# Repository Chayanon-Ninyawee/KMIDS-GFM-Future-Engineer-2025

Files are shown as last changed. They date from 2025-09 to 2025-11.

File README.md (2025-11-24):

# Hello! We are **Team KMIDS-GFM**.

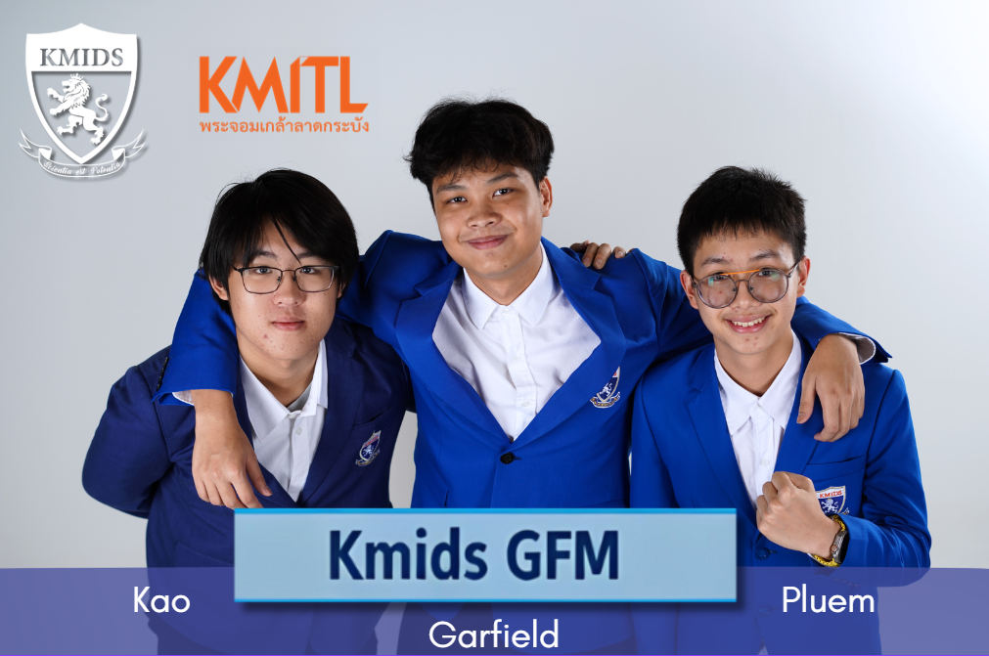
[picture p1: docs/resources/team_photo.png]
Team Photo


# WRO - Future Engineers - Robotics Project Documentation

## Team Members

- **Chayanon Ninyawee (Garfield)**
- **Supakorn Sunthonthammarat (Pleum)**
- **Thammatouch Chantasarn (Kao)**

We are a team of dedicated students with a passion for robotics and innovation. This repository documents our full engineering process, including design, components used, development, testing, and coding of our robot.

## Table of Contents

<!-- toc -->

- [1. Overview](#1-overview)
  - [1.1 About the Project](#11-about-the-project)
  - [1.2 Robot Images](#12-robot-images)
  - [1.3 Performance Video](#13-performance-video)
- [2. Mobility Management](#2-mobility-management)
  - [2.1 Drive System](#21-drive-system)
  - [2.2 Steering](#22-steering)
  - [2.3 Chassis Design](#23-chassis-design)
- [3. Power and Sense Management](#3-power-and-sense-management)
  - [3.1 Power Source](#31-power-source)
  - [3.2 Sensor and Camera](#32-sensor-and-camera)
  - [3.3 Processing Units](#33-processing-units)
  - [3.4 Circuit Diagram](#34-circuit-diagram)
  - [3.5 Power Consumption](#35-power-consumption)
- [4. Obstacle Management](#4-obstacle-management)
  - [4.1 Open Challenge](#41-open-challenge)
  - [4.2 Obstacle Challenge](#42-obstacle-challenge)
  - [4.3 Parallel Parking](#43-parallel-parking)
- [5. Source Code](#5-source-code)
  - [5.1 API Documentation](#51-api-documentation)
  - [5.2 Code Structure](#52-code-structure)
  - [5.3 Compilation / Upload Instructions](#53-compilation--upload-instructions)
- [6. List of Components](#6-list-of-components)
- [7. 3D Model Files](#7-3d-model-files)
  - [7.1 FreeCAD Files](#71-freecad-files)
  - [7.2 STL Files](#72-stl-files)
  - [7.3 Slicer Files](#73-slicer-files)
- [8. Building Instructions](#8-building-instructions)
- [9. Extras](#9-extras)

<!-- tocstop -->

## 1. Overview

### 1.1 About the Project

This project focuses on designing, building, and programming an autonomous robot capable of completing a series of complex obstacle challenges as part of the WRO Future Engineers competition.

Team KMIDS-GFM was inspired by the challenge of applying engineering principles and problem-solving skills to creatively and efficiently solve complex problems. Pushing forward with our passion for innovation and hands-on learning.

Our goal is to design and build a reliable and efficient system that demonstrates our technical and collaborative skills while serving as a learning experience. We followed a systematic process, including brainstorming, researching, prototyping, testing, and iterating. We maintained detailed documentation to facilitate knowledge sharing and ensure a smoother workflow throughout the project.

Our robot is engineered using a custom modular chassis in a rear-wheel drive configuration, controlled using a Raspberry Pi 5 and a Raspberry Pi Pico 2. It utilizes a combination of an LIDAR sensor and a fish-eye lens camera to provide an advanced system for obstacle detection and navigation.

Our objective is to create an intelligent robot that is capable of navigating through obstacles with pinpoint precision and speed.

### 1.2 Robot Images

<table>
  <tr>
    <td align="center">
      <b>Front View</b><br>
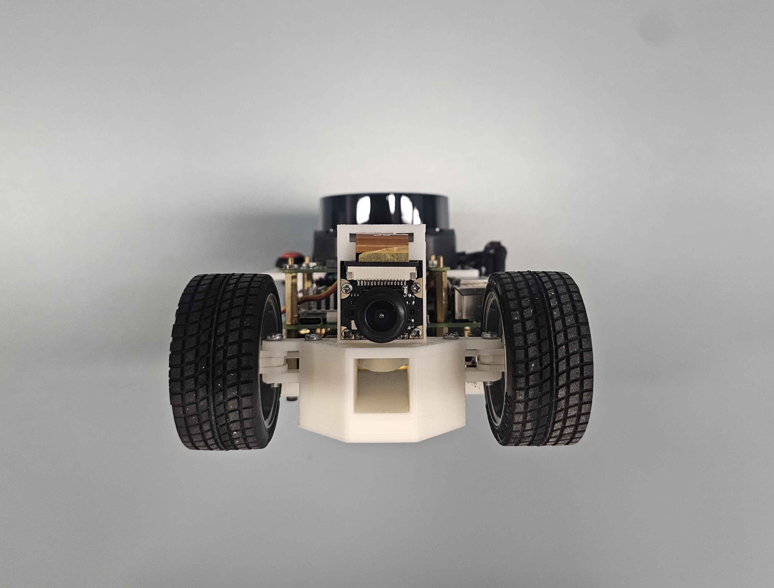
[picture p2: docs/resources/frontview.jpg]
      
    </td>
    <td align="center">
      <b>Back View</b><br>
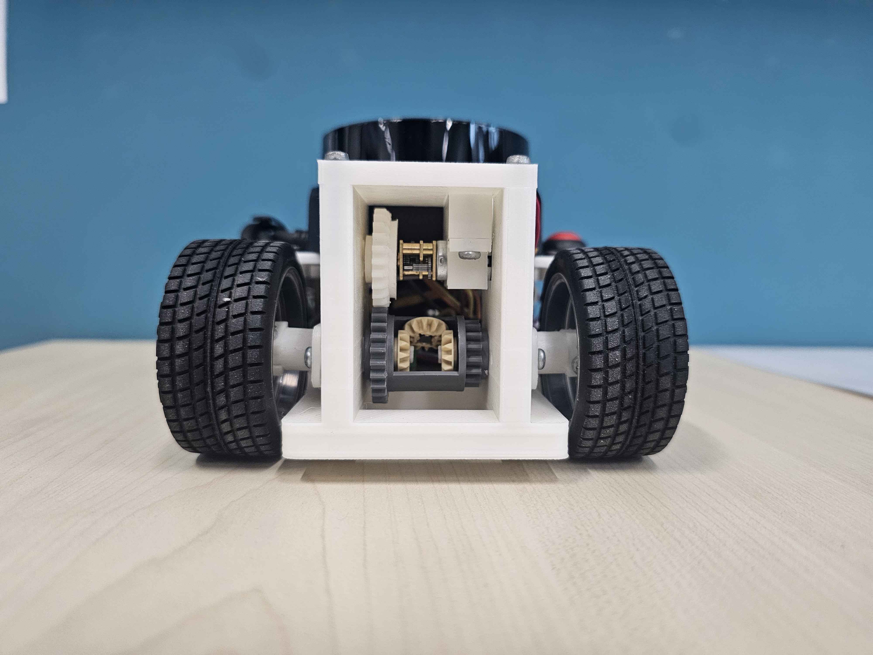
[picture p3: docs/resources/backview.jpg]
      
    </td>
    <td align="center">
      <b>Left Side View</b><br>
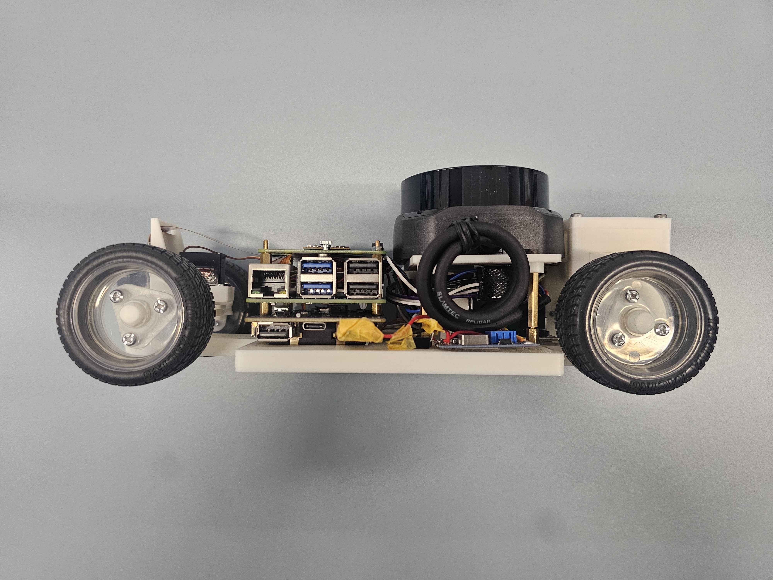
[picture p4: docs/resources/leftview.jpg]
      
    </td>
  </tr>
  <tr>
    <td align="center">
      <b>Right Side View</b><br>
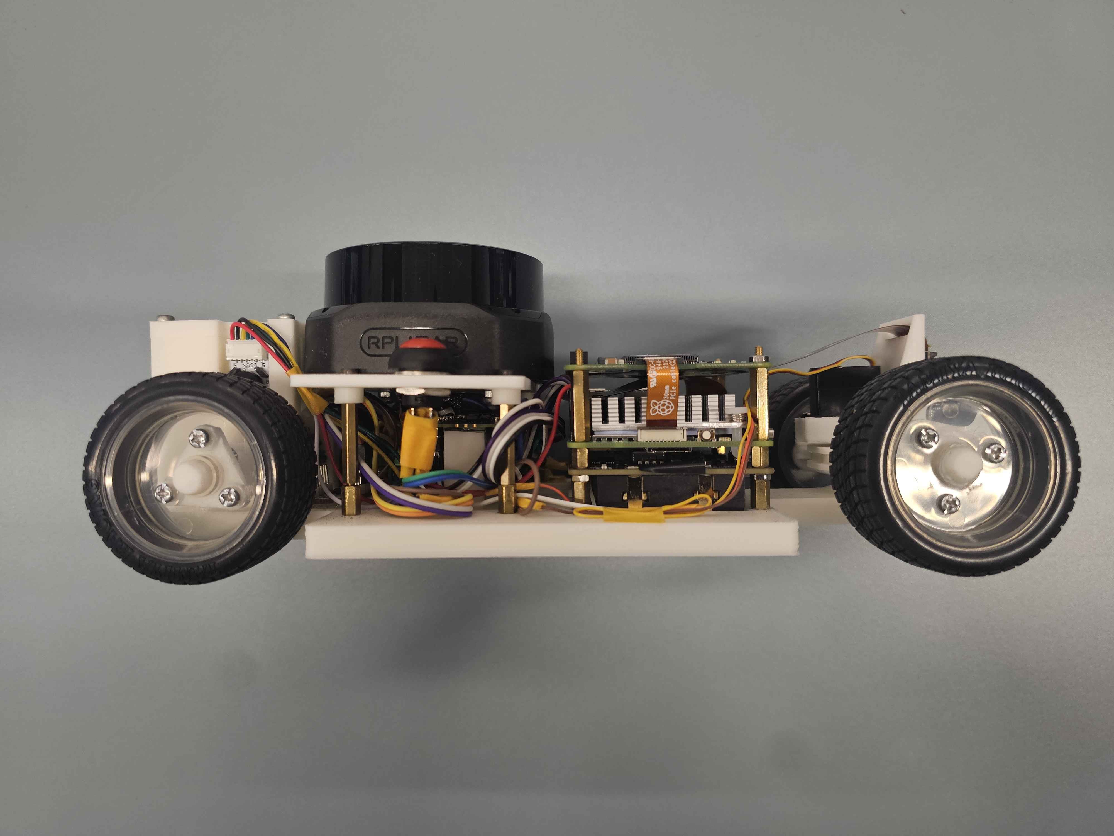
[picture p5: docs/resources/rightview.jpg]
      
    </td>
  <td align="center">
  <b>Top View</b><br>
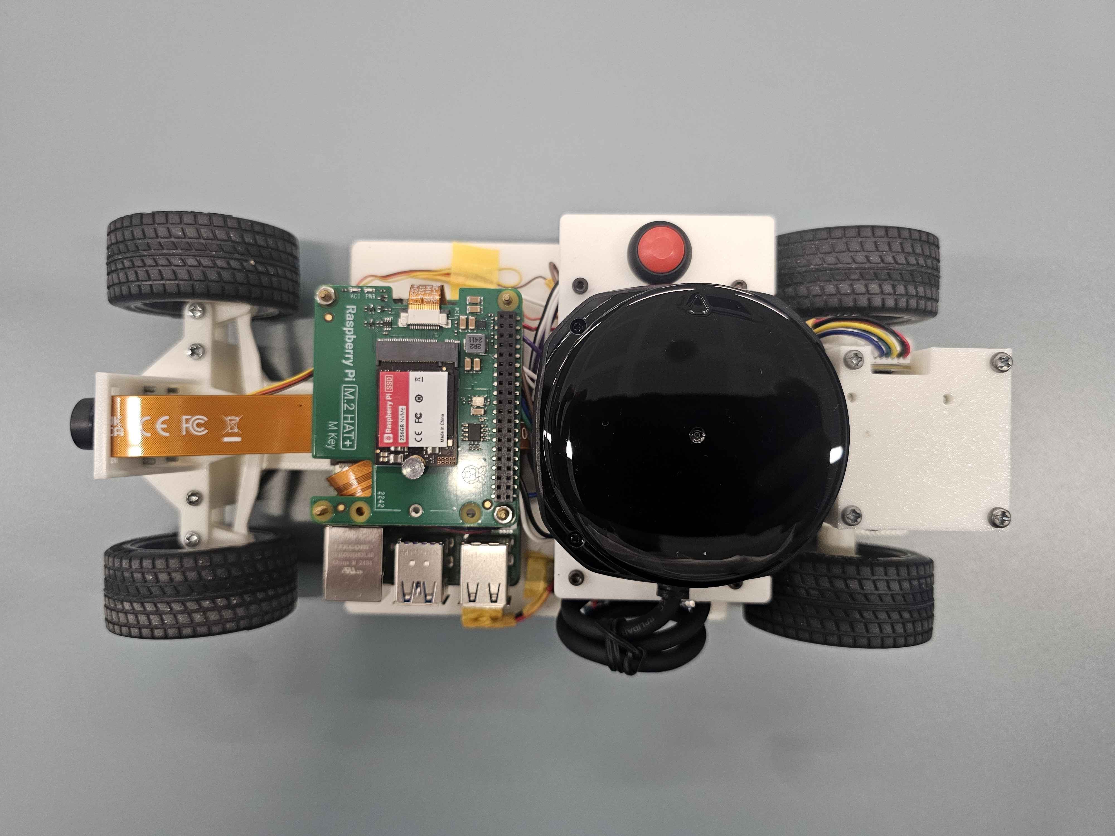
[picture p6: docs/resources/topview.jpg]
  
</td>
    <td align="center">
      <b>Bottom View</b><br>
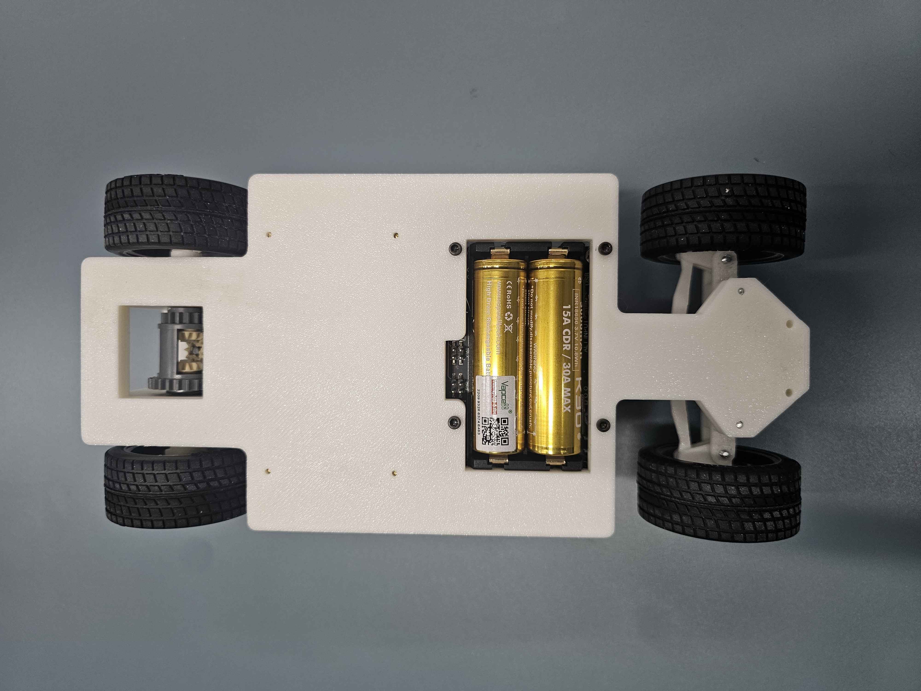
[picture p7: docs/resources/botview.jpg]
      
    </td>
  </tr>
</table>

### 1.3 Performance Video

[Part 1: Open Challenge Video](https://youtu.be/gOz7pKEmLP0)

[Part 2: Obstacle Challenge Video](https://youtu.be/q8gWAhReJgc)

These two parts show both the Open and Obstacle Challenges respectively.

<p align="right">
  <a href="#top">Back To Top</a>
</p>

## 2. Mobility Management

- **Drive System:** 2-wheel differential drive (rear wheels).
- **Steering:** Front-wheel steering using S0009m servo.

### 2.1 Drive System

**Motor: N20 Motor**

<table>
  <tr>
    <td align="center" width="300" >
      
    </td>
    <td>
      <h3>Specifications:</h3>
      <ul>
        <li>Voltage: 6V </li>
        <li>No-load Speed: 500RPM </li>
        <li>Stall Torque 0.15kg-cm</li>
        <li>Current: 0.023A</li>
        <li>Gear Ratio: 1:100</li>
      </ul>
    </td>
  </tr>
</table>

**Reason for Selection:**

- It is compact and lightweight, allowing us to fit it into our robot easily.
- Provides moderate torque that is more than enough for the flat arena.
- Easy to use on the robot and integrate with other parts.

The N20 motor is equipped with an encoder to provide precise motion feedback, ensuring the robot’s movements are accurate. The motor drives the rear wheels through a LEGO differential gear system, which allows the robot to maintain smooth and balanced turns even at higher speeds. By distributing torque between the two wheels, the differential minimizes wheel slip and ensures stability during sharp maneuvers.
The integration of encoders with the N20 motors provides real-time feedback for closed-loop control, enabling precise speed regulation and consistent lap performance. Although the torque of the N20 is modest, the combination with the differential gear makes it well-suited for the flat and predictable competition arena, striking a balance between efficiency, stability, and mechanical simplicity.

**Differential Gear:**

We used a LEGO differential gear system on our robot which allows the left and right rear wheels to rotate at different speeds while turning, preventing tire drag and ensuring smoother turning. This setup enhances maneuverability and stability, especially during tight turns in the obstacle challenge and during parallel parking.

**Mounting:**

- Installed using 3D-printed motor clamps screwed to a detachable motor plate that is placed above the differential gear compartment. This will allow for future changes to accommodate bigger motors and gears. [Motor Clamp](./FreeCAD-Files/Assembly/mesh_export/MotorHolder_1x.stl) [Motor Plate](./FreeCAD-Files/Assembly/mesh_export/MotorPlate_1x.stl)

diff gear

- Wires connected to Raspberry Pi Pico 2.
- Rubber wheels are screwed onto the motor shaft.

**Considerations:**
To reach a faster speed, we can upgrade the N20 motor to the N30, which is the easiest upgrade, providing an overall improvement in speed and torque. However, the N30 motor is typically larger and such, might need extra modifications to the robot's chassis and motor clamp to fit properly. It also generally operates at higher voltages and currents, so the power supply needs to be modified to support this upgrade.

### 2.2 Steering



**Servo: S0009M**

<table>
  <tr>
    <td align="center" width="300" >
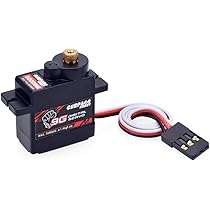
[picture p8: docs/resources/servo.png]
      
    </td>
    <td> 
      <h3>Specifications:</h3>
      <ul>
          <li>Rated Torque: 1.1kgf/cm</li>
          <li>Speed: 0.15sec/60°</li>
          <li>Voltage: 5V</li>
          <li>Gearing: Metal</li>
          <li>Type: Digital </li>
      </ul>
    </td>
  </tr>
</table>

**Reason for Selection:**

- The small size and PWM interface make it easy to control via Raspberry Pi Pico 2.
- It has sufficient torque to steer the front wheels responsively.
- It has balanced speed and stability during turns and lane changes.
- This servo is widely used in hobby robotics, and as such, there is much available documentation and mounting kits.

We considered many steering systems, but following our design principle of precision, we decided to implement Ackermann steering geometry to better replicate the precise turning behavior of real-world vehicles.

Unlike simpler systems, Ackermann steering has the advantage of smoother turns by moving each wheel at different angles in a turn, reducing the slippage of the tires and improving turn accuracy.

The fundamental principle of Ackermann geometry involves positioning the steering linkage so that a line drawn through both front wheels intersects the rear axle of the robot.



While this steering geometry is complex to implement, we believe that the advantages it provides are important — especially in obstacle navigation and parking, where precise control and a minimized turning radius are essential. It enables smoother maneuvering and accurate alignment in narrower spaces.

Our implementation comes in the form of a custom 3D-printed Ackermann steering mechanism, which offers the following key aspects:

- We used FreeCAD to experiment with different pivot points and steering angles step by step.
- Although true Ackermann geometry is difficult to achieve at our robot's small scale, we aimed to approximate the behavior through multiple design iterations.
- Adjustments were made to the servo horns and steering angles directly in CAD before testing.

**Calibration and Implementation**

To make sure the steering angle performed correctly, we carried out an iterative calibration process:

- We manually adjusted the servo horn angle and linkage positions step by step in FreeCAD until the wheels aligned at the desired steering angle.
- After each adjustment, we observed whether the wheels tracked correctly in both directions.
- Once the optimal angle is reached, we make sure to model the steering mechanism around the angle.

**Mounting:**

- Screwed directly into a platform plate in front of the chassis, connected to the steering mechanism.

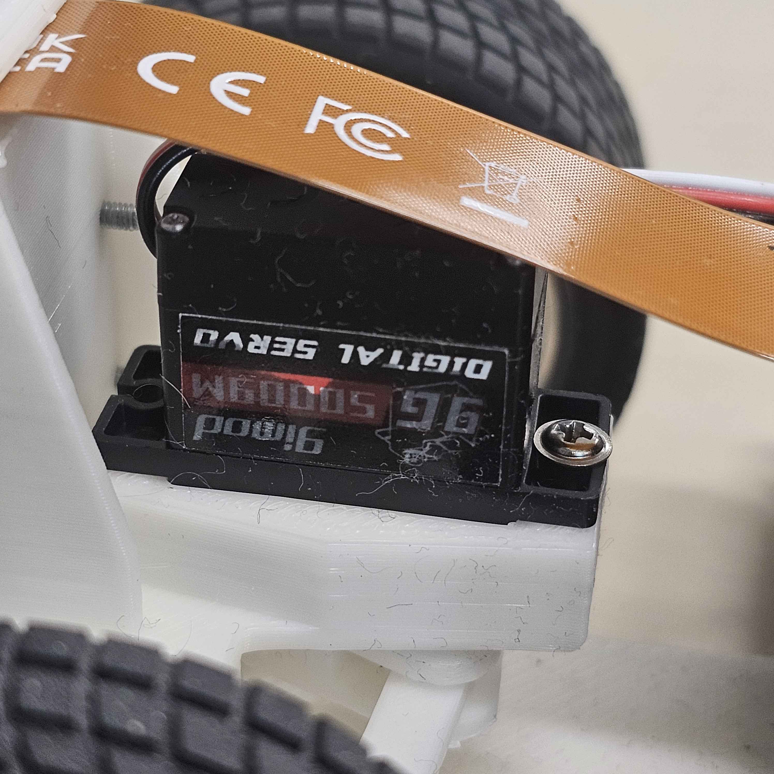
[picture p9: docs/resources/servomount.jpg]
Servo Mounting


**Considerations**
While the servo used is adequate for the task, it can still be replaced with something more precise. We plan to upgrade to a high-resolution digital servo with a narrower deadband and metal gears for more accurate movement. By also integrating a PWM driver such as the PCA9685, we gain 12-bit resolution control, which gives the robot the ability to make finer adjustments than the Raspberry Pi’s native PWM.

### 2.3 Chassis Design

**Chassis Overview:**

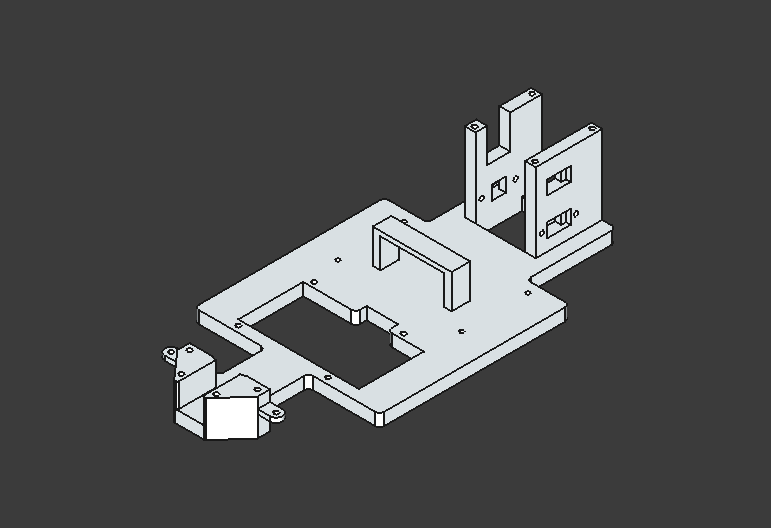
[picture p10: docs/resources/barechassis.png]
chassis


| Dimension | Value (mm) |
| --- | --- |
| Width | 244 |
| Length | 120 |
| Height | 59 |

**Design Overview**

Our chassis was designed with a focus on weight and modularity. The goal is for our chassis to be a stable platform on which we can implement the steering geometry while also allowing components to remain centered on the chassis.

**Layout**

The layout of the chassis is made to fit the rear-mounted motors and front-mounted steering mechanism. Meanwhile, electronics and sensors are mounted in the center for ease of wiring.

Our robot chassis was completely custom-designed in FreeCAD and 3D printed using [esun PLA+](https://esun3dstore.com/products/pla-pro), which we found is easy to print with, offering a smoother texture and less warping compared to ABS, while also being lightweight and durable. Alongside the main chassis, the drivetrain and steering modules are mounted on our 3D-printed detachable plates that were fine-tuned during testing to achieve the correct alignment with other components. Other components, such as motor clamps and sensor brackets, are designed as independent printable components. The chassis was also designed with modularity in mind for replacements and upgrades, with reduced overhangs for printing ease.

<p align="right">
  <a href="#top">Back To Top</a>
</p>

## 3. Power and Sense Management

### 3.1 Power Source

**Battery: 18650 Lithium-ion**

<table>
  <tr>
    <td align="center" width="300" >
      
    </td>
    <td>
      <h3>Specifications:</h3>
      <ul>
          <li>Capacity: 2000 mAh</li>
          <li>Normal voltage: 3.7V</li>
          <li>Standard discharge: 10A </li>
          <li>Weight: 48g</li>
      </ul>
    </td>
  </tr>
</table>

The power and sensor systems are crucial to the vehicle's ability to navigate the challenges of the competition. For this project, our vehicle is powered by an [EP-0136 Raspberry Pi UPS](https://wiki.52pi.com/index.php?title=EP-0136) (Uninterruptible Power Supply), with 2x 18650 Lithium-ion as the energy source. The UPS maintains a stable 5V output to the Raspberry Pi 5 even during fluctuations. It also has built-in charging and voltage regulation circuits, allowing continuous operation while also recharging the batteries when external power is connected.
The batteries are connected in series to provide a nominal voltage of 7.4V and a combined capacity of around 4000 mAh, depending on the cells used. This setup is capable of delivering a continuous current of around 20 Amps, which is sufficient to supply to the robot for various tasks. This setup ensures that the Raspberry Pi won't shut down unexpectedly, allowing uninterrupted data processing and decision-making throughout the run.

The motors, however, require a higher voltage — at least 6V, and to ensure reliable performance, the N20 motor power is supplied through a step-up converter that increases 5V to 12V. Because the motor power is separate from the Raspberry Pi, the standard on/off switch could not fully control the system. To solve this, a MOSFET and a 4.4 kΩ resistor were added between the gate and source, with the drain connected to the negative side of the step-up converter. This allows the robot to be safely powered on and off while supplying sufficient power to both the Raspberry Pi and the motors.

The onboard processing unit, the Raspberry Pi 5, serves as the vehicle's brain. Raspberry Pi recommends a 5V 5A power supply. This is well within the limits of what the two batteries can provide.

 

**Motor Driver: DRV8871**

<table>
  <tr>
    <td align="center" width="300">
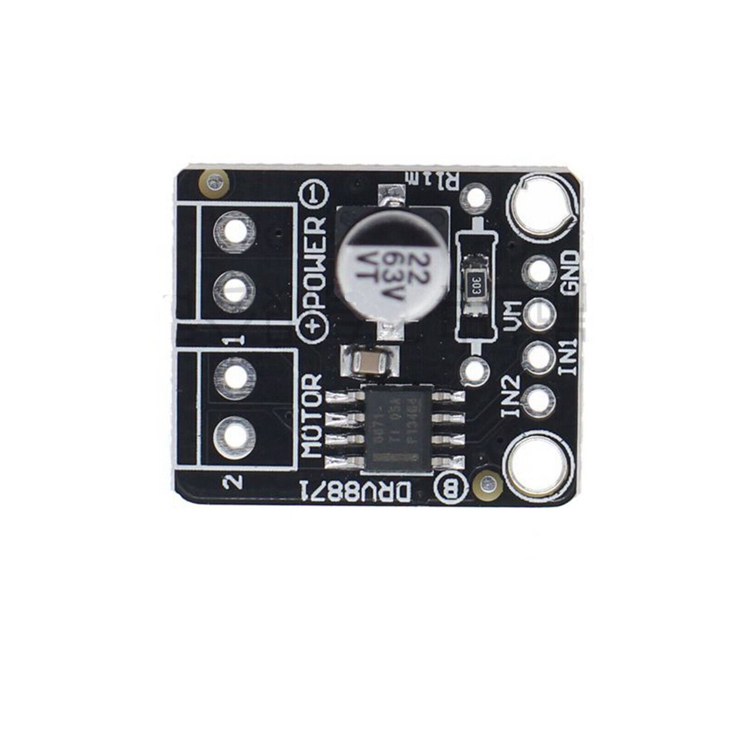
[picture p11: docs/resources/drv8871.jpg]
      
    </td>
    <td>
      <h3>Specifications:</h3>
      <ul>
          <li>Operating Voltage Range: 6.5V – 45V</li>
          <li>Peak Output Current: 3.6A</li>
          <li>Typical R<sub>DS(on)</sub> (high + low): 565mΩ</li>
          <li>Logic Level Input Voltage: Up to 5.5V on IN pins </li>
      </ul>
      </ul>
    </td>
  </tr>
</table>

**Transistor: N-Channel MOSFET**

<table>
  <tr>
    <td align="center" width="300">
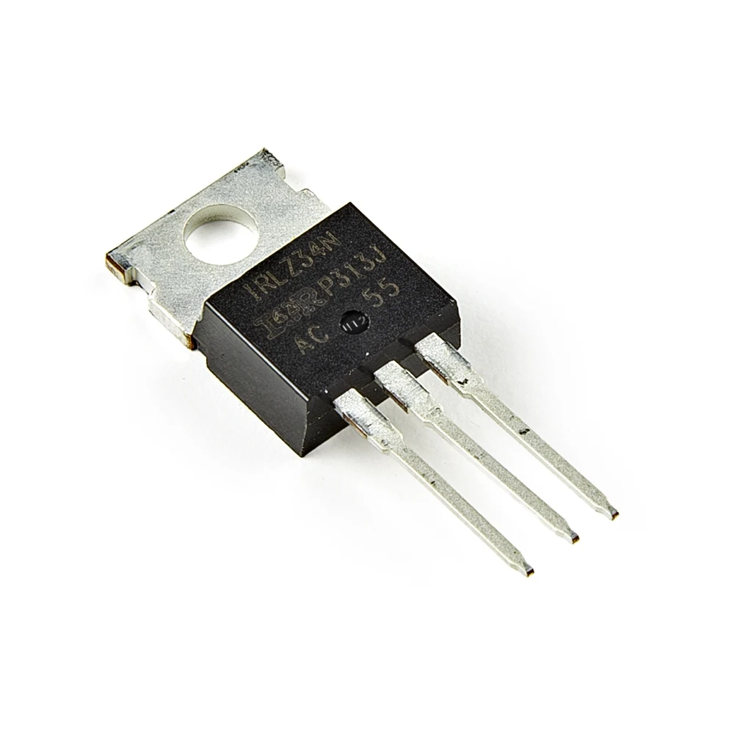
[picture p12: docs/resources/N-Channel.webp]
      
    </td>
    <td>
      <h3>Specifications:</h3>
      <ul>
          <li>Type: N-Channel Enhancement Mode MOSFET</li>
          <li>Drain-Source Voltage (Vds): 30V ~ 60V </li>
          <li>Continuous Drain Current (Id): 20A ~ 40A</li>
          <li>Gate Threshold Voltage (Vgs(th)): 1V ~ 3V</li>
          <li>R<sub>DS(On-Resistance)</sub>: 0.02Ω ~ 0.05Ω </li>
          <li>Gate-Source Voltage (Vgs max): ±20V</li>
          <li>Power Dissipation: 30W ~ 60W</li>
          <li>Package Type: TO-220 / TO-247 (common formats)</li>
          <li>Typical Applications: Motor drivers, power switching, DC-DC converters</li>
      </ul>
    </td>
  </tr>
</table>

### 3.2 Sensor and Camera

**LIDAR Sensor: RPLIDAR S2**

<table>
  <tr>
    <td align="center" width="300" >
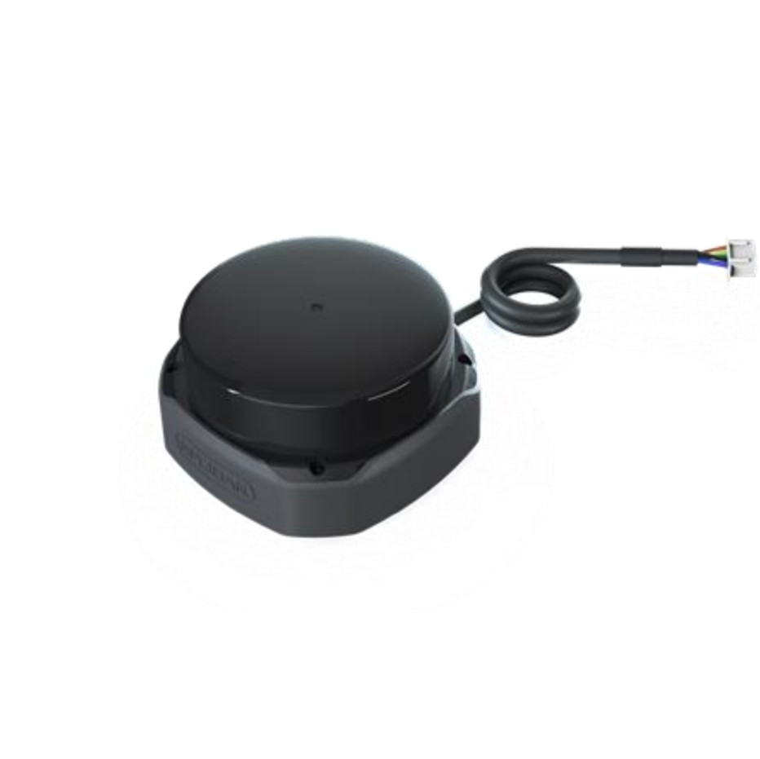
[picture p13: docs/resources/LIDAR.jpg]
      
    </td>
    <td>
      <h3>Specifications:</h3>
      <ul>
        <li>Distance Range:
          <ul>
            <li>White: 0.05-30m（90% Reflection）</li>
            <li>Black: 0.05-10m（10% Reflection）</li>
          </ul>
        </li>
        <li>Angle Resolution: 0.1125°</li>
        <li>Accuracy: ±30mm</li>
        <li>Scan Rate: 10Hz</li>
        <li>Distance Resolution: 13mm</li>
        <li>Discharge Rate: 30C</li>
        <br/><br/>
      </ul>
    </td>
  </tr>
</table>

**Reason for Selection:**

- **Precise distance measurement** of obstacles within a wide radius
- **360° scanning** makes it ideal for SLAM (Simultaneous Localisation and Mapping).
- **Compact size and lightweightness** allow easy fitting on our robot.
- **Fast sampling rate** allows real-time mapping and obstacle avoidance.

**The LIDAR sensor is used mainly for the following tasks:**

- Wall following and collision Avoidance

- Obstacle detection

- Identify parking spaces and assist with parallel parking.

- Mapping and determining initial orientation

**Camera: Fish-Eye Lens Raspberry Pi 5MP IR Camera**

<table >
  <tr>
    <td align="center" width="300" >
      
    </td>
    <td >
      <h3>Specifications:</h3>
      <ul>
        <li>Voltage: 6V</li>
        <li>Resolution: 5MP </li>
        <li>Focal Length: Adjustable</li>
        <li>Image Sensor: OV5647</li>
        <li>Aperture: F2.35</li>
      </ul>
    </td>
  </tr>
</table>

**Reason for Selection:**

- **130° wide field of view** from the fish-eye lens captures a large area for tracking compared to a regular lens.
- **Infrared compatibility** enables low-light vision.
- **High-resolution (5MP)** provides a clear image for the robot.
- **Compact size** fits well on our robot and is lightweight.

This setup allows for a wide-angle view, enhancing environmental awareness during both the Open Challenge and Obstacle Challenge. The camera identifies course elements such as walls, pillars, colored markers, parking spaces, and lane lines.

**The camera is used mainly for the following tasks:**

- Detect and differentiate wall positions.

- Identify pillar colors and types.

- Recognize parking zones.

- Track path lines and boundaries.

**Gyroscope and Orientation Sensor: BNO085**

<table>
  <tr>
    <td align="center" width="300">
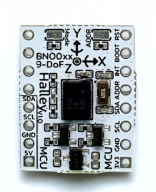
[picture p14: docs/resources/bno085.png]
      
    </td>
    <td>
      <h3>Specifications:</h3>
      <ul>
        <li>Sensor Type: 9-axis IMU (3-axis accelerometer, 3-axis gyroscope, 3-axis magnetometer)</li>
        <li>Processor: ARM Cortex-M0 with integrated CEVA SH-2 sensor fusion firmware</li>
        <li>Interfaces: I²C, SPI, UART (RVC Mode)</li>
        <li>Operating Voltage: 3.3V </li>
        <li>Key Features: Absolute orientation, linear acceleration, gravity vector, motion and step detection</li>
      </ul>
    </td>
  </tr>
</table>

The BNO085 is a compact 9-axis IMU sensor that combines an accelerometer, gyroscope, and magnetometer with an onboard processor running advanced sensor fusion algorithms. It provides stable and drift-compensated orientation data, including rotation vectors, linear acceleration, and gravity direction without requiring complex external calculations.

We mounted the BNO085 near the center of the chassis. It communicates with the Raspberry Pi Pico 2 via the I²C interface, continuously providing real-time orientation and angular velocity data. This helps the robot maintain correct heading, and smooth out steering adjustments which are crucial especially during obstacle navigation.

### 3.3 Processing Units

**Single Board Computer: Raspberry Pi 5**

<table>
  <tr>
    <td align="center" width="300" >
      INSERT RP5
    </td>
    <td>
      <h3>Specifications:</h3>
      <ul>
        <li>Quad-core Arm Cortex-A76 CPU @ 2.4GHz</li>
        <li>8GB LPDDR4X RAM</li>
        <li>Dual 4K HDMI output (60fps)</li>
        <li>PCIe 2.0 support via FPC connector</li>
        <li>2x USB 3.0 ports, 2x USB 2.0 ports</li>
      </ul>
    </td>
  </tr>
</table>

The Raspberry Pi 5 serves as the robot’s main processing unit, responsible for high-level decision-making, image processing, and sensor data integration.\
With its powerful quad-core Arm Cortex-A76 CPU with 8GB RAM, it can efficiently handle real-time LIDAR and camera data for tasks such as mapping, obstacle avoidance, and path planning.\
Its small size allows easy mounting on the chassis without adding significant weight.

**Microcontroller: Raspberry Pi Pico 2**

<table>
  <tr>
    <td align="center" width="300" >
      INSERT RPP2
    </td>
    <td>
      <h3>Specifications:</h3>
      <ul>
        <li>Dual ARM Cortex-M33</li>
        <li>4 MB QSPI flash memory</li>
        <li>520KB SRAM</li>
        <li>2.4GHz 802.11n wireless LAN</li>
        <li>26 multi-function GPIO pins</li>
      </ul>
    </td>
  </tr>
</table>

The Raspberry Pi Pico 2 acts as the robot’s low-level controller, managing tasks such as motor control, servo steering, and sensor input.\
It communicates with the Raspberry Pi 5 via UART, and divides high-level processing and precise hardware control.\
It provides reliable and responsive control for driving and steering functions, ensuring smoother and more accurate movement.

**Adapter Board: Raspberry Pi M.2 HAT+**

<table>
  <tr>
    <td align="center" width="300" >
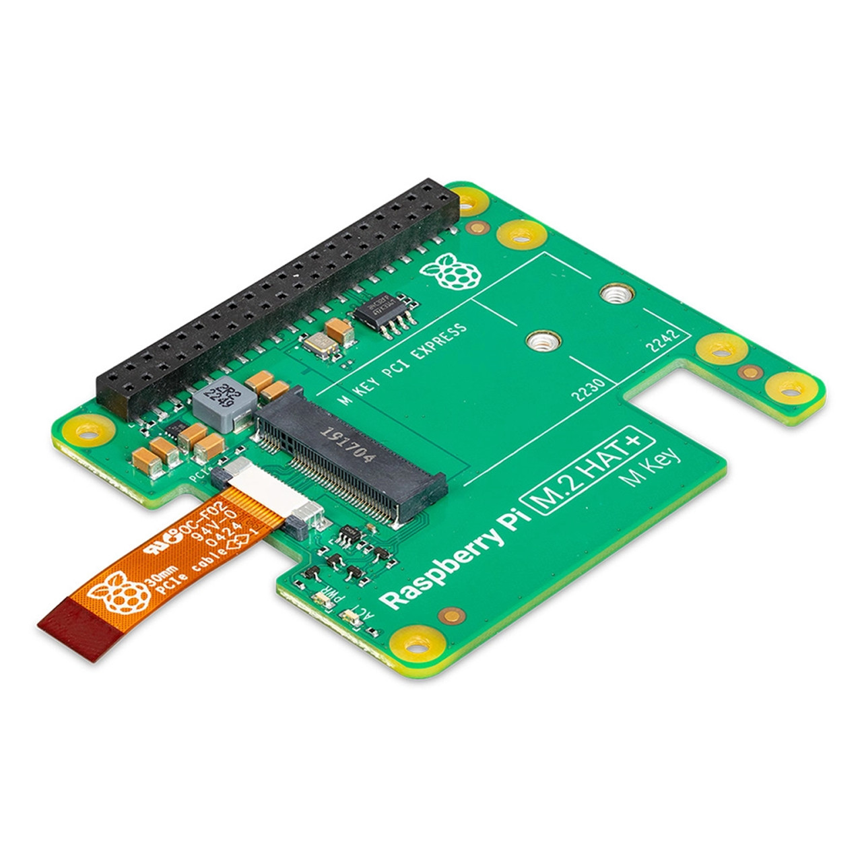
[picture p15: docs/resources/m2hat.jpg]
INSERT m2hat
      
    </td>
    <td>
      <h3>Specifications:</h3>
      <ul>
          <li>Interface: PCIe 2.0 x1 (via 16-pin FPC connector)</li>
          <li>Supported Devices: NVMe M.2 M-key SSDs (2280/2242/2230 sizes)</li>
          <li>Data Transfer Rate: Up to 5 Gbps</li>
          <li>Power Supply: 3.3V from Raspberry Pi 5 (max 2A output)</li>
      </ul>
    </td>
  </tr>
</table>

The Raspberry Pi M.2 HAT+ extends the system’s capabilities by enabling high-speed PCIe 2.0 connectivity for M.2 NVMe SSDs.\
This allows the robot to store and access large volumes of sensor and mapping data quickly, especially with the LIDAR sensor, improving runtime performance and reducing data bottlenecks during complex operations.

### 3.4 Circuit Diagram

**Wiring Diagram:**

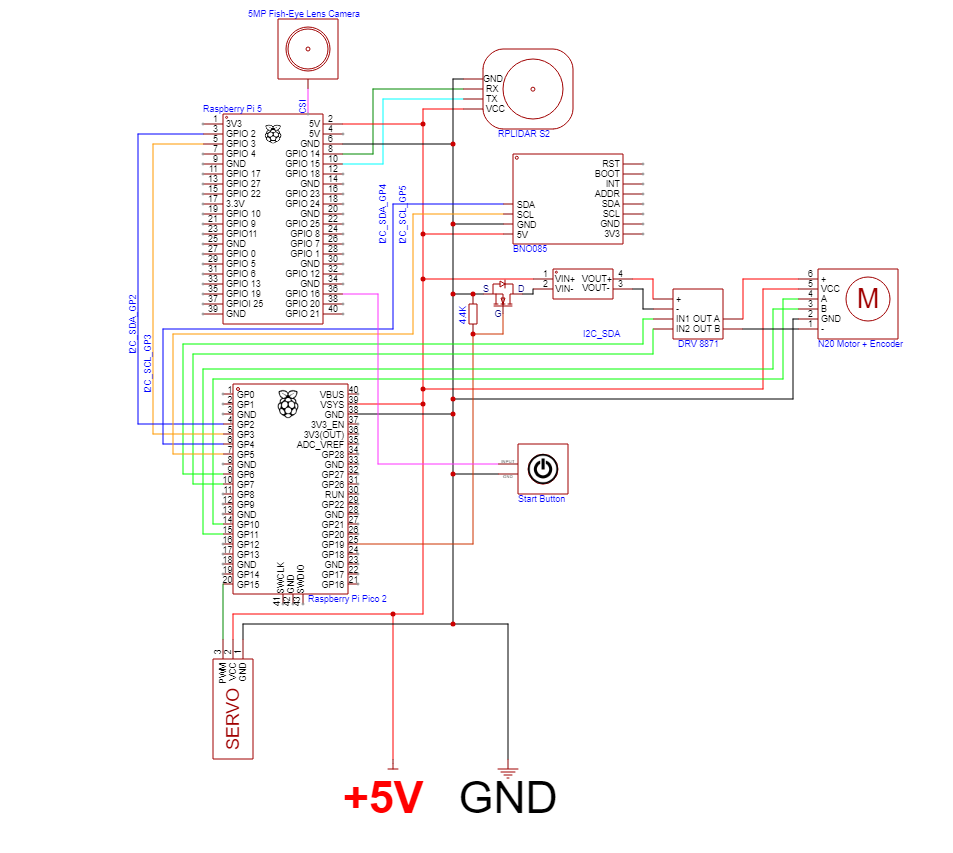
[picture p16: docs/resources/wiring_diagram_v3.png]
Wiring diagram pic


We had to decide on whether to do a PCB or use jumper wires to connect each component. In the end, we settled on using jumper wires as it gives us more flexibility during our development in case an error happens, and allows us to troubleshoot each part easily without having to redesign the circuit board.

### 3.5 Power Consumption

| Component | Supply (V) | Typical Current (A) | Peak Current (A) | Typical Power (W) |
|---|---|---|---|---|
| Raspberry Pi 5 | 5 | 2.50 | 5.00 | 12.50 |
| Raspberry Pi Pico 2 | 5 | 0.05 | 0.10 | 0.25 |
| RPLIDAR S2 | 5 | 0.45 | 0.60 | 2.25 |
| 5MP Fish-Eye Lens Camera | 5 | 0.12 | 0.25 | 0.60 |
| BNO085 IMU | 3.3 | 0.015 | 0.025 | 0.05 |
| Micro Servo S0009M (steering) | 5 | 0.12 | 0.65 | 0.60 |
| N20 DC Motor | 12 | 0.30 | 1.50 | 7.20 |
| DRV8871 Motor Driver | 12 | 0.01 | 0.04 | 0.24 |
| Raspberry Pi M.2 HAT+ | 3.3 | 0.25 | 1.00 | 3.30 |
| Step-Up Converter | — | — | — | η ≈ 88% |

<p align="right">
  <a href="#top">Back To Top</a>
</p>

## 4. Obstacle Management

There are two challenges in this competition:

- The **open challenge** involves the robot completing three full laps around the field without touching the wall. The size of each side of the field and the direction in which the car drives are randomised.
- The **obstacle challenge** requires the robot to complete three laps while avoiding the traffic signs. If the sign is red, then the robot must traverse on the right side and if the pillar is green, the robot must traverse on the left. The direction in which the car drives and the placement of the signs are randomised. After the third lap, the car must find the parking area and park in the area without touching the surrounding barriers around it.

Our implementation relies heavily on the RPLIDAR S2 sensor and the fish-eye lens camera for continuous environment scanning, which helps the algorithm decide the movement of the robot.

We divide the strategy into three phases:

- Open Challenge
- Obstacle Challenge
- Parallel Parking Maneuver

### 4.1 Open Challenge

Robot navigating Open Challenge

*Figure: Example of robot sensing walls and navigating the field.*

The Open Challenge requires the robot to complete three laps around the arena without touching the walls. The driving direction is randomised at the start, so relying on pre-programmed movements is not feasible

The robot determines which direction to turn by analysing the walls detected around it. The algorithm works as follows:

1. **Check for empty walls:**

   - If there are no front walls or no side walls, the function returns `std::nullopt` because it cannot determine a turn direction.

1. **Identify the closest front wall:**

   - Compares all front wall line segments and selects the one with the highest midpoint (largest Y value).
   - Determines the left and right points of this front wall based on their X coordinates.

1. **Evaluate left walls:**

   - Finds the "higher" point of each left wall line segment.
   - Uses `perpendicularDirection` and `perpendicularDistance` to determine if a left turn is feasible.
   - Returns `COUNTER_CLOCKWISE` if a left turn is clear, or `CLOCKWISE` if blocked.

1. **Evaluate right walls:**

   - Similarly, checks the right wall line segments.
   - Returns `CLOCKWISE` if a right turn is clear, or `COUNTER_CLOCKWISE` if blocked.

1. **Fallback:**

   - If no rules match, returns `std::nullopt`, indicating that the turn direction cannot be determined.

<details>
<summary><b><span style="font-size:1.2em; background-color:#f2f2f2; padding:4px 8px; border-radius:5px;"> Click here to show C++ code</span></b></summary>

getTurnDirection code (from [lidar_processor.h](code/raspberry-pi-5/src/processors/lidar/lidar_processor.h) / [lidar_processor.cpp](code/raspberry-pi-5/src/processors/lidar/lidar_processor.cpp))

```cpp
/**
 * @brief Determine the robot's turn direction based on relative walls.
 *
 * @param walls Resolved or candidate walls around the robot.
 * @return Optional RotationDirection; empty if turn direction can't be determined.
 */
std::optional<RotationDirection> getTurnDirection(const RelativeWalls &walls) {
    if (walls.frontWalls.empty()) return std::nullopt;
    if (walls.leftWalls.empty() && walls.rightWalls.empty()) return std::nullopt;

    // Pick the highest front line
    const LineSegment *frontLine = &walls.frontWalls[0];
    float frontMidY = (frontLine->y1 + frontLine->y2) / 2.0f;
    for (const auto &line : walls.frontWalls) {
        float midY = (line.y1 + line.y2) / 2.0f;
        if (midY > frontMidY) {
            frontLine = &line;
            frontMidY = midY;
        }
    }

    // Determine left and right points of the front line
    float frontLeftX, frontLeftY, frontRightX, frontRightY;
    if (frontLine->x1 < frontLine->x2) {
        frontLeftX = frontLine->x1;
        frontLeftY = frontLine->y1;
        frontRightX = frontLine->x2;
        frontRightY = frontLine->y2;
    } else {
        frontLeftX = frontLine->x2;
        frontLeftY = frontLine->y2;
        frontRightX = frontLine->x1;
        frontRightY = frontLine->y1;
    }

    // Check left walls
    for (const auto &leftLine : walls.leftWalls) {
        float leftHigherX, leftHigherY;
        if (leftLine.y1 < leftLine.y2) {
            leftHigherX = leftLine.x1;
            leftHigherY = leftLine.y1;
        } else {
            leftHigherX = leftLine.x2;
            leftHigherY = leftLine.y2;
        }

        // Check for left wall that is far away in x direction from front wall
        float dir = leftLine.perpendicularDirection(frontLeftX, frontLeftY);
        if (dir > 90.0f && dir < 270.0f) {
            if (leftLine.perpendicularDistance(0.0f, 0.0f) > 1.70f) return RotationDirection::COUNTER_CLOCKWISE;

            continue;
        }

        if (frontLine->perpendicularDistance(leftHigherX, leftHigherY) < 0.30) return RotationDirection::CLOCKWISE;

        if (leftLine.perpendicularDistance(frontLeftX, frontLeftY) > 0.30f) {
            float dir = leftLine.perpendicularDirection(frontLeftX, frontLeftY);
            if (dir > 270.0f || dir < 90.0f) return RotationDirection::COUNTER_CLOCKWISE;
        }
    }

    // Check right walls
    for (const auto &rightLine : walls.rightWalls) {
        float rightHigherX, rightHigherY;
        if (rightLine.y1 < rightLine.y2) {
            rightHigherX = rightLine.x1;
            rightHigherY = rightLine.y1;
        } else {
            rightHigherX = rightLine.x2;
            rightHigherY = rightLine.y2;
        }

        // Check for right wall that is far away in x direction from front wall
        float dir = rightLine.perpendicularDirection(frontRightX, frontRightY);
        if (dir > 270.0f || dir < 90.0f) {
            if (rightLine.perpendicularDistance(0.0f, 0.0f) > 1.70f) return RotationDirection::CLOCKWISE;

            continue;
        }

        if (frontLine->perpendicularDistance(rightHigherX, rightHigherY) < 0.30) return RotationDirection::COUNTER_CLOCKWISE;

        if (rightLine.perpendicularDistance(frontRightX, frontRightY) > 0.30f) {
            float dir = rightLine.perpendicularDirection(frontRightX, frontRightY);
            if (dir > 90.0f && dir < 270.0f) return RotationDirection::CLOCKWISE;
        }
    }

    return std::nullopt;  // unknown if no rule matched
}
```

</details>

### 4.2 Obstacle Challenge

LIDAR view
Camera view

*Figure: Example of the robot detecting traffic lights.*

The Obstacle Challenge requires the robot to navigate the arena while avoiding obstacles and detecting traffic lights. The robot combines LIDAR and camera data to make real-time decisions. The main processing steps are:

1. **Determine turn direction**

   - Uses the same algorithm as in the Open Challenge to decide whether to turn CLOCKWISE or COUNTER_CLOCKWISE based on the surrounding walls.
   - If no clear direction is detected, the default is CLOCKWISE.

1. **Convert LIDAR data to Cartesian coordinates**

   - LIDAR points that are too close (< 0.005 m), too far (> 3.2 m), or outside the forward scanning range are ignored.
   - Converts polar coordinates (distance, angle) to Cartesian coordinates relative to the robot.

1. **Filter points based on walls and turn direction**

   - Depending on the current turn direction, left, right, and far walls are used to remove points that are too close to obstacles.
   - Thresholds (`outerEdge = 0.30 m`, `innerEdge = 0.70 m`) define valid regions for candidate traffic lights.

1. **Cluster nearby LIDAR points**

   - Points within `distanceThreshold` (default 0.05 m) are grouped together.
   - Each cluster is averaged to generate a candidate traffic light location.

1. **Filter camera colors**

   - The camera frame is converted to HSV color space.
   - Thresholded for red, green, and pink colors.
   - The top 50% of the frame is blacked out to reduce noise from the ceiling or irrelevant background.
   - Contours are extracted, and only those larger than the `areaThreshold` are kept.

1. **Combine camera and LIDAR data**

   - For each detected camera block (red/green), find the closest LIDAR point within a maximum allowed horizontal angle difference.
   - Only the nearest point along the ray is matched to prevent duplicate detections.
   - Returns a vector of `TrafficLightInfo` containing both the LIDAR location and the camera block information.

1. **Decision making**

   - Using the combined traffic light data, the robot can identify which traffic light is relevant for its current path.
   - Integrates turn direction, obstacle positions, and traffic light locations to navigate safely and efficiently.

<details>
<summary><b><span style="font-size:1.2em; background-color:#f2f2f2; padding:4px 8px; border-radius:5px;"> Click here to show C++ code for Obstacle Challenge processing</span></b></summary>

getTrafficLightPoints code (from [lidar_processor.h](code/raspberry-pi-5/src/processors/lidar/lidar_processor.h) / [lidar_processor.cpp](code/raspberry-pi-5/src/processors/lidar/lidar_processor.cpp)) <!--TODO: Add link to the actual file-->

```cpp
/**
 * @brief Detect traffic light points from LIDAR data and resolved walls.
 *
 * @param timedLidarData LIDAR scan data with timestamps.
 * @param resolveWalls Resolved walls around the robot.
 * @param turnDirection Optional turn direction of the robot (if has no value, assume CLOCKWISE).
 * @param distanceThreshold Maximum distance between points to cluster into a single traffic light point.
 * @return Vector of 2D points representing detected traffic light locations.
 */
std::vector<cv::Point2f> getTrafficLightPoints(
    const TimedLidarData &timedLidarData,
    const ResolvedWalls resolveWalls,
    std::optional<RotationDirection> turnDirection,
    float distanceThreshold
) {
    // Convert polar to Cartesian (in meters)
    std::vector<cv::Point2f> points;
    points.reserve(timedLidarData.lidarData.size());

    for (const auto &node : timedLidarData.lidarData) {
        // TODO: Change this value to fit the actual robot
        if (node.distance < 0.005) continue;
        if (node.distance > 3.200) continue;
        if (node.angle > 5 && node.angle < 175 && node.distance > 0.700) continue;

        float rad = node.angle * static_cast<float>(M_PI) / 180.0f;

        float lidarX = node.distance * std::sin(rad);
        float lidarY = node.distance * std::cos(rad);
        float x, y;
        lidarToCartesian(lidarX, lidarY, x, y);

        points.emplace_back(x, y);
    }

    std::vector<cv::Point2f> filteredPoints;
    for (auto &point : points) {
        if (not resolveWalls.frontWall) return {};
        float frontDistance = resolveWalls.frontWall->perpendicularDistance(point.x, point.y);

        std::optional<LineSegment> outerWall, innerWall, farOuterWall;
        if (turnDirection.value_or(RotationDirection::CLOCKWISE) == RotationDirection::CLOCKWISE) {
            outerWall = resolveWalls.leftWall;
            innerWall = resolveWalls.rightWall;

            farOuterWall = resolveWalls.farRightWall;
        } else {
            outerWall = resolveWalls.rightWall;
            innerWall = resolveWalls.leftWall;

            farOuterWall = resolveWalls.farLeftWall;
        }

        float outerDistance;
        if (outerWall) {
            outerDistance = outerWall->perpendicularDistance(point.x, point.y);
        } else if (innerWall) {
            outerDistance = 1.00f - innerWall->perpendicularDistance(point.x, point.y);
        } else {
            return {};
        }

        // TODO: Clean up this magic number
        const float outerEdge = 0.30f;
        const float innerEdge = 0.70f;

        if (farOuterWall) {
            float outerFarDistance = farOuterWall->perpendicularDistance(point.x, point.y);

            if (frontDistance < outerEdge or frontDistance > 3.00f - outerEdge or outerDistance < outerEdge or outerFarDistance < outerEdge)
                continue;
            if (frontDistance > innerEdge and outerDistance > innerEdge and outerFarDistance > innerEdge) continue;
        } else {
            if (frontDistance < outerEdge or frontDistance > 3.00f - outerEdge or outerDistance < outerEdge or
                outerDistance > 3.00f - outerEdge)
                continue;
            if (frontDistance > innerEdge and outerDistance > innerEdge) continue;
        }

        filteredPoints.push_back(point);
    }

    std::vector<cv::Point2f> averages;
    if (filteredPoints.empty()) return averages;

    std::vector<cv::Point2f> currentCluster;
    currentCluster.push_back(filteredPoints[0]);

    for (size_t i = 1; i < filteredPoints.size(); ++i) {
        cv::Point2f p1 = currentCluster.back();
        cv::Point2f p2 = filteredPoints[i];

        float dist = std::hypot(p2.x - p1.x, p2.y - p1.y);

        if (dist < distanceThreshold) {
            currentCluster.push_back(p2);
        } else {
            // compute average for current cluster
            float sumX = 0, sumY = 0;
            for (auto &p : currentCluster) {
                sumX += p.x;
                sumY += p.y;
            }
            averages.emplace_back(sumX / currentCluster.size(), sumY / currentCluster.size());

            // start new cluster
            currentCluster.clear();
            currentCluster.push_back(p2);
        }
    }

    // handle last cluster
    if (!currentCluster.empty()) {
        float sumX = 0, sumY = 0;
        for (auto &p : currentCluster) {
            sumX += p.x;
            sumY += p.y;
        }
        averages.emplace_back(sumX / currentCluster.size(), sumY / currentCluster.size());
    }

    return averages;
}
```

filterColors code (from [lidar_processor.h](code/raspberry-pi-5/src/processors/lidar/lidar_processor.h) / [lidar_processor.cpp](code/raspberry-pi-5/src/processors/lidar/lidar_processor.cpp)) <!--TODO: Add link to the actual file-->

```cpp
/**
 * @brief Filters an input frame for red, green, and pink colors and extracts contours.
 *
 * The input frame is converted to HSV color space, thresholded into binary masks
 * for each target color (red, green, pink), and processed to extract contour
 * centroids and areas. Contours smaller than the given area threshold are discarded.
 *
 * @param timedFrame Input frame with timestamp and image data.
 * @param areaThreshold Minimum area threshold (in pixels) to filter out small/noisy contours.
 * @return ColorMasks A struct containing masks and contour info for red, green, and pink.
 */
ColorMasks filterColors(const TimedFrame &timedFrame, double areaThreshold) {
    const cv::Mat &input = timedFrame.frame;

    CV_Assert(!input.empty());
    CV_Assert(input.type() == CV_8UC3);

    // Fill the top part with black
    int topRows = static_cast<int>(input.rows * 0.50);
    input(cv::Rect(0, 0, input.cols, topRows)) = cv::Scalar(0, 0, 0);

    cv::Mat hsv;
    cv::cvtColor(input, hsv, cv::COLOR_BGR2HSV);

    // Red
    cv::Mat maskRed1, maskRed2, maskRed;
    cv::inRange(hsv, lowerRed1Light, upperRed1Light, maskRed1);
    cv::inRange(hsv, lowerRed2Light, upperRed2Light, maskRed2);
    cv::bitwise_or(maskRed1, maskRed2, maskRed);

    // Green
    cv::Mat maskGreen1, maskGreen2, maskGreen;
    cv::inRange(hsv, lowerGreen1Light, upperGreen1Light, maskGreen1);
    cv::inRange(hsv, lowerGreen2Light, upperGreen2Light, maskGreen2);
    cv::bitwise_or(maskGreen1, maskGreen2, maskGreen);

    return {{extractContoursInfo(maskRed, areaThreshold), maskRed}, {extractContoursInfo(maskGreen, areaThreshold), maskGreen}};
}
```

combineTrafficLightInfo code (from [lidar_processor.h](code/raspberry-pi-5/src/processors/lidar/lidar_processor.h) / [lidar_processor.cpp](code/raspberry-pi-5/src/processors/lidar/lidar_processor.cpp)) <!--TODO: Add link to the actual file-->

```cpp
/**
 * @brief Combine camera block angles and LIDAR traffic light points.
 *
 * Only returns traffic lights that have a matching camera block based on horizontal angle.
 * The LIDAR points are assumed to be in the LIDAR coordinate frame, and the camera may be
 * offset relative to the LIDAR. The function accounts for this offset when computing angles.
 *
 * @param blockAngles Vector of camera BlockAngle (red/green blocks).
 * @param lidarPoints Vector of 2D points from LIDAR (traffic lights), in LIDAR coordinates.
 * @param cameraOffset Position of the camera relative to the LIDAR (x, y) in LIDAR coordinates.
 * @param maxAngleDiff Maximum allowed difference in angle (radians) to consider a camera block
 *                     as corresponding to a LIDAR point.
 * @return std::vector<TrafficLightInfo> Combined information for traffic lights that have
 *                                      matching camera blocks.
 */
std::vector<TrafficLightInfo> combineTrafficLightInfo(
    const std::vector<camera_processor::BlockAngle> &blockAngles,
    const std::vector<cv::Point2f> &lidarPoints,
    cv::Point2f cameraOffset,
    float maxAngleDiff
) {
    std::vector<TrafficLightInfo> results;
    std::vector<cv::Point2f> availableLidar = lidarPoints;

    for (const auto &block : blockAngles) {
        size_t bestIndex = std::numeric_limits<size_t>::max();
        float smallestDiff = std::numeric_limits<float>::max();
        float closestDistance = std::numeric_limits<float>::max();

        // Loop over all available LIDAR points
        for (size_t i = 0; i < availableLidar.size(); ++i) {
            const auto &lp = availableLidar[i];
            float dx = lp.x - cameraOffset.x;
            float dy = lp.y - cameraOffset.y;

            float lidarAngle = std::atan2(dy, dx);  // radians
            float lidarAngleDeg = lidarAngle * 180.0f / M_PI;

            float angleDiff = std::abs(90.0f - block.angle - lidarAngleDeg);

            if (angleDiff <= maxAngleDiff) {
                float distanceAlongRay = std::sqrt(dx * dx + dy * dy);  // distance from camera to LIDAR point

                // Pick the closest along the ray (smallest distance)
                if (distanceAlongRay < closestDistance || angleDiff < smallestDiff) {
                    closestDistance = distanceAlongRay;
                    smallestDiff = angleDiff;
                    bestIndex = i;
                }
            }
        }

        if (bestIndex != std::numeric_limits<size_t>::max()) {
            results.push_back(TrafficLightInfo{availableLidar[bestIndex], block});
            availableLidar.erase(availableLidar.begin() + bestIndex);  // consume
        }
    }

    return results;
}
```

</details>

### 4.3 Parallel Parking

 <!--TODO:-->

<!--### 4.4 Advanced Use: Converting Raw Lidar Data to Useful Data

TBA. TODO:-->

<p align="right">
  <a href="#top">Back To Top</a>
</p>

## 5. Source Code

### 5.1 API Documentation

[**[CLICK HERE] Link to the API Documentation**](code/README.md)

> This section will detail the ins and out of the various codes used in the robot

### 5.2 Code Structure

All the code used in the robot can be found [here](code)

The project codebase is organized to separate different components, challenges, and hardware targets. The main folders are `raspberry-pi-5`, `raspberry-pi-pico-2`, and `shared`. The `shared` folder contains code used by both hardware targets.

```txt
repo-root
└─ code
   ├─ raspberry-pi-5
   │  ├─ apps
   │  │  ├─ challenges
   │  │  │  ├─ open_challenge      # Executable for open challenge
   │  │  │  └─ obstacle_challenge  # Executable for obstacle challenge
   │  │  ├─ log_viewer             # Applications to visualise logs
   │  │  ├─ scan_map_inner         # Inner map scanning tools
   │  │  ├─ scan_map_outer         # Outer map scanning tools
   │  │  ├─ test_camera            # Camera testing app
   │  │  ├─ test_i2c               # I2C communication testing
   │  │  ├─ test_lidar             # LIDAR testing app
   │  │  └─ test_lidar_cam         # Combined LIDAR + camera testing
   │  ├─ external
   │  │  ├─ lccv                   # External library (depends on libcamera)
   │  │  └─ rplidar_sdk            # RPLIDAR SDK (external, Make-based)
   │  ├─ scripts
   │  │  ├─ check_battery_status.py
   │  │  ├─ shutdown.sh
   │  │  └─ ups_shutdown.py
   │  ├─ src
   │  │  ├─ modules
   │  │  │  ├─ camera
   │  │  │  ├─ i2c_master
   │  │  │  ├─ lidar
   │  │  │  └─ pico2
   │  │  │     └─ CMakeLists.txt
   │  │  ├─ processors
   │  │  │  ├─ camera
   │  │  │  ├─ combined
   │  │  │  ├─ lidar
   │  │  │  └─ CMakeLists.txt
   │  │  ├─ types
   │  │  │  ├─ camera_struct.h
   │  │  │  ├─ lidar_struct.h
   │  │  │  ├─ pico2_struct.h
   │  │  │  └─ robot_pose_struct.h
   │  │  └─ utils
   │  │     ├─ direction
   │  │     ├─ log_reader
   │  │     ├─ logger
   │  │     ├─ pid_controller
   │  │     ├─ ring_buffer
   │  │     └─ CMakeLists.txt
   │  └─ CMakeLists.txt
   │  └─ build.sh
   │
   ├─ raspberry-pi-pico-2
   │  ├─ external
   │  │  ├─ BNO08x_Pico_Library
   │  │  └─ pico-sdk
   │  ├─ src
   │  │  ├─ modules
   │  │  │  ├─ controllers
   │  │  │  └─ i2c_slave
   │  │  ├─ utils
   │  │  │  └─ pid_controller
   │  │  └─ CMakeLists.txt
   │  ├─ main.cpp
   │  └─ CMakeLists.txt
   │  └─ build.sh
   │
   └─ shared                # Shared code used by both Pi 5 and Pi Pico
      ├─ i2c
      └─ types
```

**Notes on structure:**

- **`apps/`**: Executables for tests, challenges, and log visualization (Pi 5-specific).
- **`external/`**: Third-party libraries like LCCV, RPLIDAR SDK, Pico SDK.
- **`scripts/`**: System control scripts (shutdown, battery check, etc.).
- **`src/modules/`**: Hardware-specific functional modules.
- **`src/processors/`**: Data processing pipelines (camera, LIDAR, combined sensors).
- **`src/types/`**: Data structure headers for the local target.
- **`src/utils/`**: Utility classes (PID controllers, logging, ring buffers).
- **`shared/`**: Code reused by both `raspberry-pi-5` and `raspberry-pi-pico-2` (I²C handling, types).
- **`build.sh` & `CMakeLists.txt`**: Build scripts for each hardware target.

This structure allows Pi 5 and Pi Pico to share common code while keeping hardware-specific modules separate.

### 5.3 Compilation / Upload Instructions

This section describes how to build and run the project on the **Raspberry Pi 5** and **Raspberry Pi Pico 2**, including all dependencies.

**Dependencies**

**Git Submodules (must initialise and update recursively):**

```bash
git submodule update --init --recursive
```

**Raspberry Pi 5 specific:**

- **RPLIDAR SDK** – For LIDAR functionality.
- **LCCV** – Custom computer vision library that depends on **libcamera**.
- **System libraries (install separately):**
  - **OpenCV** – For camera image processing. The installation guide can be found [here](https://docs.opencv.org/4.x/d3/d52/tutorial_windows_install.html)
  - **libcamera** – Required by LCCV for camera capture. The installation guide can be found [here](https://libcamera.org/getting-started.html)

**Raspberry Pi Pico 2 specific:**

- **Pico SDK** – Required for building Pico firmware.
- **BNO08x_Pico_Library** – IMU library for Pico.

**Raspberry Pi 5 Build**

1. Go to the Pi 5 project directory:

```bash
cd ~/git/KMIDS-GFM-Future-Engineer-2025/code/raspberry-pi-5
```

2. Make the build script executable:

```bash
chmod +x build-arm64.sh 
```

3. Build all targets:

```bash
./build-arm64.sh
```

4. Executables are generated in the `build/` directory according to the CMake output settings.

**Note:** To make builds faster and reproducible, we compile the Raspberry Pi binaries on a development machine using Docker. This avoids the need to install heavy build tools on the Pi itself.

We follow the method from [rolandsdev.blog](https://rolandsdev.blog/posts/cross-compile-for-raspberry-pi-with-docker/).

**Raspberry Pi Pico 2 Build & Upload**

1. Go to the Pico project directory:

```bash
cd ~/git/KMIDS-GFM-Future-Engineer-2025/code/raspberry-pi-pico-2
```

2. Make the build script executable:

```bash
chmod +x build.sh
```

3. Build all targets:

```bash
./build.sh
```

4. Upload the compiled UF2 file to the Pico:

```bash
sudo picotool load build/gfm_pico_2.uf2 -f
```

> Note: The UF2 file path should match the output name specified in the Pico CMakeLists.txt.

<p align="right">
  <a href="#top">Back To Top</a>
</p>

## 6. List of Components

| Component | Quantity | Source/Supplier |
|---|---|---|
| Raspberry Pi 5 | 1 | [Gammaco](https://gammaco.com/gammaco/Raspberry_Pi_GB_89RD014.html) |
| Raspberry Pi Pico 2 | 1 | [Cytron](https://th.cytron.io/p-raspberry-pi-pico2-board) |
| UPS EP-0136 | 1 | [52Pi](https://52pi.com/products/52pi-ups-board-with-rtc-coulometer-for-raspberry-pi) |
| 18650 Lithium-ion Battery | 2 | [Cytron](https://th.cytron.io/p-3.7v-2000mah-li-ion-battery) |
| RPLidar S2 | 1 | [SLAMTEC](https://www.slamtec.com/en/S2) |
| 5MP Fish-Eye Camera | 1 | [Cytron](https://th.cytron.io/p-fish-eye-lense-raspberry-pi-5mp-ir-camera?r=1&language=en-gb&gad_campaignid=18809653822) |
| BNO085 IMU | 1 | [Shopee](https://shopee.co.th/%E0%B9%82%E0%B8%A1%E0%B8%94%E0%B8%B9%E0%B8%A5-AR-VR-BNO055-BNO085-BNO086-%E0%B8%8A%E0%B8%B4%E0%B8%9E%E0%B9%81%E0%B8%97%E0%B9%89-%E0%B8%A3%E0%B8%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) |
| S0009M Servo | 1 | [Shopee](https://shopee.co.th/Surpass-HOBBY-9G-%E0%B8%94%E0%B8%B4%E0%B8%88%E0%B8%B4%E0%B8%95%E0%B8%AD%E0%B8%A5%E0%B8%81%E0%B8%B1%E0%B8%99%E0%B8%99%E0%B9%89%E0%B9%8D%E0%B8%B2-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) |
| N20 DC Motor + Encoder | 2 | [Shopee](https://shopee.co.th/product/627316253/26413874397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) |
| Raspberry Pi M.2 HAT+ | 1 | [Shopee](https://shopee.co.th/product/1157514659/25882329690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) |
| DRV8871 Motor Driver | 1 | [Shopee](https://shopee.co.th/product/1032045852/43908925373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) |
| DC-DC Boost Step-Up Module | 1 | N/A |
| N-Channel MOSFET Transistor | 1 | N/A |
| 4.4 kΩ Resistor | 1 | N/A |
| Wires | Various | N/A |
| eSUN PLA+ Spool | 1–3 | [eSUN](https://www.esun3d.com/pla-pro-product/) |
| Screws (M2 & M2.6 & M3) | Various | N/A |
| Tape | Various | N/A |
| Lithium Grease | Small | N/A |

**Printers Used:**

- [Bambu Lab P1S](https://asia.store.bambulab.com/products/p1s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)

- [Creality Ender 3 V3 KE](https://store.creality.com/products/ender-3-v3-ke-3d-printer)

  <p align="right">
  <a href="#top">Back To Top</a>

</p>

## 7. 3D Model Files

### 7.1 FreeCAD Files

We used FreeCAD to design the 3D models used to make the robot. The files can be found [here](./FreeCAD-Files)

- [**Assembly Files**](FreeCAD-Files/Assembly) - contains the full robot assembly including the part placements.
- [**Individual Parts**](FreeCAD-Files/Parts) - includes each 3D component separately.

### 7.2 STL Files

**Chassis & Core Structure**

- [`Chassis_1x.stl`](FreeCAD-Files/Assembly/mesh_export/Chassis_1x.stl)
- [`FrontCover_1x.stl`](FreeCAD-Files/Assembly/mesh_export/FrontCover_1x.stl)
- [`AxleHolder_3x.stl`](FreeCAD-Files/Assembly/mesh_export/AxleHolder_3x.stl)

**Motor & Transmission**

- [`MotorGear_1x.stl`](FreeCAD-Files/Assembly/mesh_export/MotorGear_1x.stl)
- [`MotorHolder_1x.stl`](FreeCAD-Files/Assembly/mesh_export/MotorHolder_1x.stl)
- [`MotorPlate_1x.stl`](FreeCAD-Files/Assembly/mesh_export/MotorPlate_1x.stl)

**Wheel & Axle Components**

- [`BackWheelAxle_2x.stl`](FreeCAD-Files/Assembly/mesh_export/BackWheelAxle_2x.stl)
- [`BackWheelConnector_2x.stl`](FreeCAD-Files/Assembly/mesh_export/BackWheelConnector_2x.stl)
- [`BackWheelStopper_2x.stl`](FreeCAD-Files/Assembly/mesh_export/BackWheelStopper_2x.stl)
- [`FrontWheelAxleLeft_1x.stl`](FreeCAD-Files/Assembly/mesh_export/FrontWheelAxleLeft_1x.stl)
- [`FrontWheelAxleRight_1x.stl`](FreeCAD-Files/Assembly/mesh_export/FrontWheelAxleRight_1x.stl)
- [`FrontWheelStopper_2x.stl`](FreeCAD-Files/Assembly/mesh_export/FrontWheelStopper_2x.stl)

**Steering Linkages**

- [`TBoneLinkageBottom_1x.stl`](FreeCAD-Files/Assembly/mesh_export/TBoneLinkageBottom_1x.stl)
- [`TBoneLinkageTop_1x.stl`](FreeCAD-Files/Assembly/mesh_export/TBoneLinkageTop_1x.stl)
- [`TransferLinkageLeft_1x.stl`](FreeCAD-Files/Assembly/mesh_export/TransferLinkageLeft_1x.stl)
- [`TransferLinkageRight_1x.stl`](FreeCAD-Files/Assembly/mesh_export/TransferLinkageRight_1x.stl)
- [`WheelLinkageBottomLeft_1x.stl`](FreeCAD-Files/Assembly/mesh_export/WheelLinkageBottomLeft_1x.stl)
- [`WheelLinkageBottomRight_1x.stl`](FreeCAD-Files/Assembly/mesh_export/WheelLinkageBottomRight_1x.stl)
- [`WheelLinkageTopLeft_1x.stl`](FreeCAD-Files/Assembly/mesh_export/WheelLinkageTopLeft_1x.stl)
- [`WheelLinkageTopRight_1x.stl`](FreeCAD-Files/Assembly/mesh_export/WheelLinkageTopRight_1x.stl)

**Miscellaneous**

- [`LidarPlate_1x.stl`](FreeCAD-Files/Assembly/mesh_export/LidarPlate_1x.stl)

### 7.3 Slicer Files

All slicer project files (`.3mf`) used for printing the robot’s components can be found [here](./Slicer-Files).\
These files contain optimized slicing settings such as layer height, infill, support, and print orientation for each part.

**Chassis**

- [`Main chassis`](<Slicer-Files/Bambu_Lab_P1S_(Bambu_Slicer)/Chassis_1x.3mf>)
- [`Front cover (for camera and steering)`](<Slicer-Files%5CEnder_3_V3_KE_(Cura_Slicer)%5CCE3V3KE_FrontCover_1x.3mf>)
- [`Lidar plate`](<Slicer-Files%5CEnder_3_V3_KE_(Cura_Slicer)%5CCE3V3KE_LidarPlate_1x.3mf>)

**Mobility and Steering**

- [`Motor Gear`](<Slicer-Files%5CEnder_3_V3_KE_(Cura_Slicer)%5CCE3V3KE_MotorGear_1x.3mf>)
- [`Motor holder`](<Slicer-Files%5CEnder_3_V3_KE_(Cura_Slicer)%5CCE3V3KE_AxleHolder_MotorHolder.3mf>)
- [`Linkage parts`](<Slicer-Files%5CEnder_3_V3_KE_(Cura_Slicer)%5CCE3V3KE_Linkages.3mf>)
- [`Motor plate`](<Slicer-Files%5CEnder_3_V3_KE_(Cura_Slicer)%5CCE3V3KE_MotorPlate_1x.3mf>)
- [`Rear wheel mounts`](<Slicer-Files%5CEnder_3_V3_KE_(Cura_Slicer)%5CCE3V3KE_BackWheelStuff.3mf>)

<p align="right">
  <a href="#top">Back To Top</a>
</p>

## 8. Building Instructions

**Step 0: Print the 3D parts**

Before assembly, prepare the components listed above and print the 3D parts.

**[Chassis](<Slicer-Files/Bambu_Lab_P1S_(Bambu_Slicer)/gcode-files>) - Bambu Lab P1S**

**[Parts](<Slicer-Files/Ender_3_V3_KE_(Cura_Slicer)/gcode-files>) - Creality Ender 3 V3 KE**

<details>

<summary> <b><span style="font-size:1.1em; background-color:#f2f2f2; padding:4px 8px; border-radius:5px;">Click here to show the 3D printed parts used in the building process</span></b></summary>

</summary>

| Part Name | Quantity |
| --- | --- |
| Axle Holder | 3 |
| Back Wheel Axle | 2 |
| Back Wheel Connector | 2 |
| Back Wheel Stopper | 2 |
| Chassis | 1 |
| Front Cover | 1 |
| Front Wheel Axle (Left) | 1 |
| Front Wheel Axle (Right) | 1 |
| Front Wheel Stopper | 2 |
| Lidar Plate | 1 |
| Motor Gear | 1 |
| Motor Holder | 1 |
| Motor Plate | 1 |
| T-Bone Linkage (Bottom) | 1 |
| T-Bone Linkage (Top) | 1 |
| Transfer Linkage (Left) | 1 |
| Transfer Linkage (Right) | 1 |
| Wheel Linkage (Bottom Left) | 1 |
| Wheel Linkage (Bottom Right) | 1 |
| Wheel Linkage (Top Left) | 1 |
| Wheel Linkage (Top Right) | 1 |

</details>

**The recommended settings can be found in the slicer files. The recommended basic settings are as follows:**

<details>
<summary> Chassis </summary>

| Setting | Value |
| --- | --- |
| Layer Height | 0.3 |
| Infill Density | 25% |
| Infill Pattern | Gyroid |
| Support Type | Tree |
| Build Plate Adhesion Type | None |

</details>

<details>
<summary> Motor Gear</summary>

| Setting | Value |
| --- | ----- |
| Layer Height | 0.2 |
| Infill Density | 20% |
| Infill Pattern | Lines |
| Support Type | None |
| Build Plate Adhesion Type | Brim |

</details>

<details>
<summary> Axle holder </summary>

| Setting | Value |
| --- | ----- |
| Layer Height | 0.2 |
| Infill Density | 20% |
| Infill Pattern | Cubic |
| Support Type | None |
| Build Plate Adhesion Type | Brim |

</details>

<details>
<summary> Linkage & Back Wheel Components </summary>

| Setting | Value |
| --- | --- |
| Layer Height | 0.2 |
| Infill Density | 20% |
| Infill Pattern | Cubic |
| Support Type | Normal |
| Build Plate Adhesion Type | Brim |

</details>

<details>
<summary> Front Cover </summary>

| Setting | Value |
| --- | --- |
| Layer Height | 0.2 |
| Infill Density | 20% |
| Infill Pattern | Cubic |
| Support Type | Normal |
| Build Plate Adhesion Type | None |

</details>

<details>

<summary> LIDAR Plate & Motor Plate</summary>

| Setting | Value |
| --- | ----- |
| Layer Height | 0.2 |
| Infill Density | 20% |
| Infill Pattern | Cubic |
| Support Type | Tree |
| Build Plate Adhesion Type | None |

</details>

**Step 1: Assemble the steering system**

1. At the front, combine the wheel linkage by connecting the wheel axle and steering linkage between the two wheel linkages

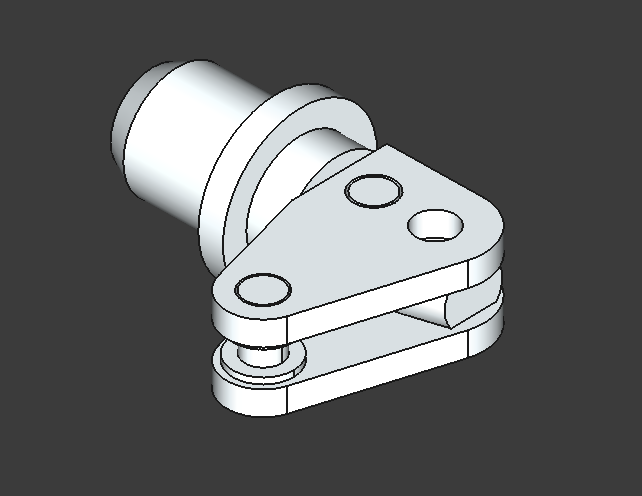
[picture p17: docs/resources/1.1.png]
   

1. Attach the steering linkage to the T-bone linkage.

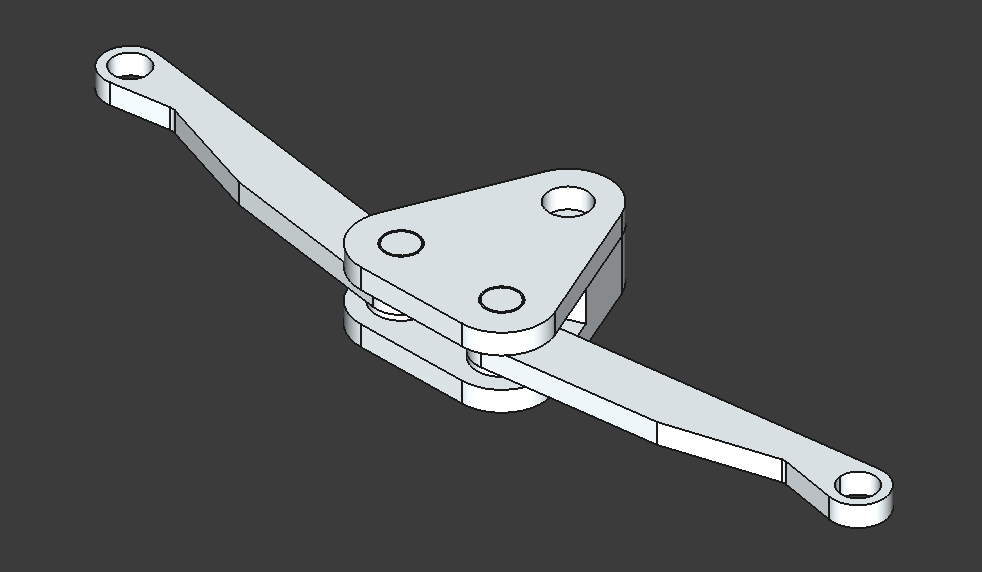
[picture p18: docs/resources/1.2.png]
   

1. Glue the two T-bone linkage parts together using glue.

1. Mount the front plate on the chassis, while securing the wheel linkage in between the chassis and front plate using 2x M3 screws.
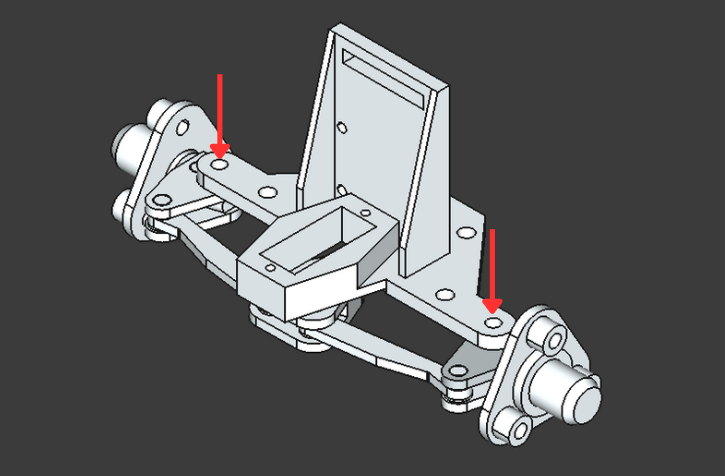
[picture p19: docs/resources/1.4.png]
   

1. Attach the servo to the front plate using 2x M1.6 screws, using glue to attach the shaft to the T-bone linkage below.

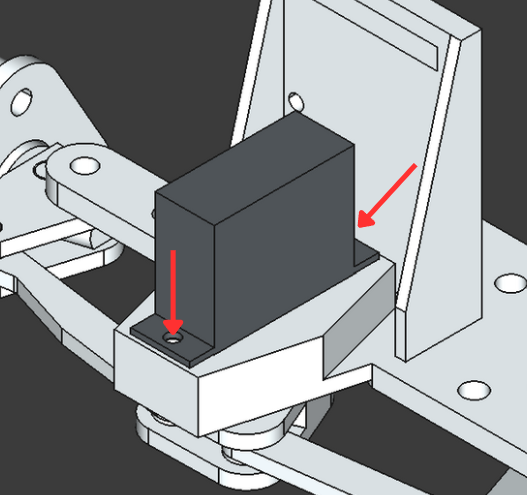
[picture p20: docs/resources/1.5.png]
   

1. Fix the wheels in place using the wheel stoppers, securing them using 3x M3 screws on each side.
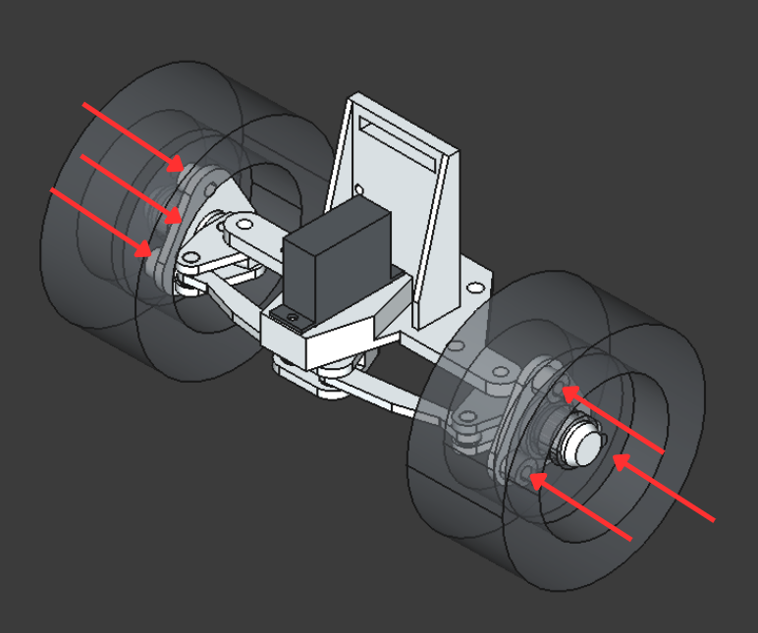
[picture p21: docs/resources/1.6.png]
   

**Step 2: Assemble the drivetrain**

1. Attach the rear wheel axles to the connector using 2x M3 screws.

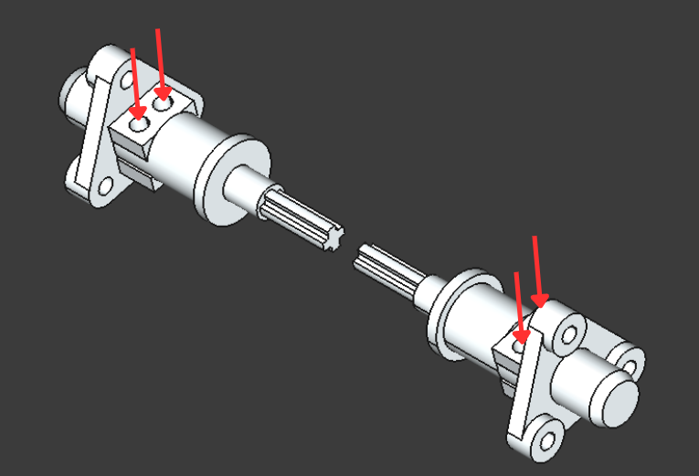
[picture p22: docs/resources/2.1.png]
   

1. Place a LEGO differential gear in between the rear wheel chassis walls, and insert the connector into the chassis wall, securing it using the stopper and 2x M3 screws on each side.

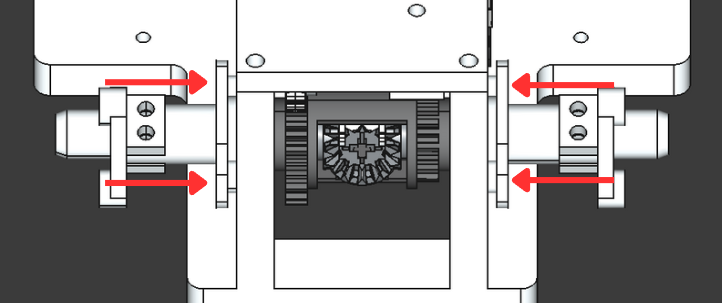
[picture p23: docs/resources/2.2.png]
   

1. Place the N20 motor into the motor plate. Secure the motor with the motor clamp using 2x M3 screws.
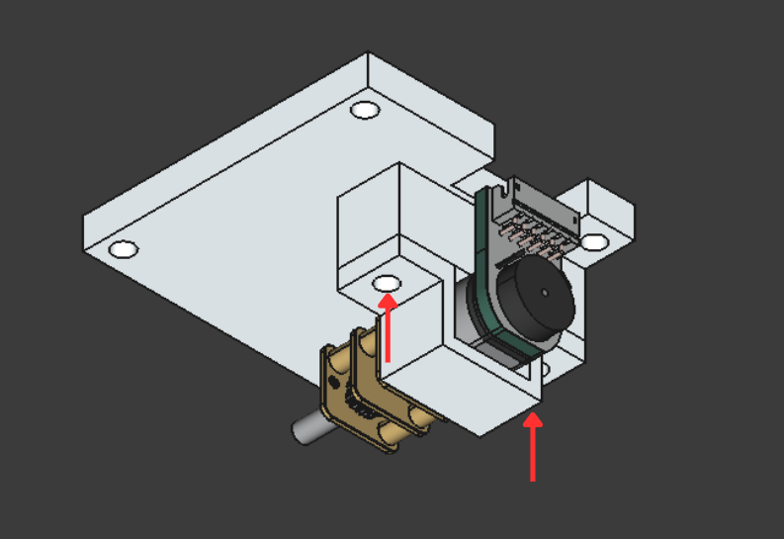
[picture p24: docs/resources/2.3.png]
   

1. Attach the 3D printed gear to the motor and secure the motor plate onto the chassis using 4x M3 screws.
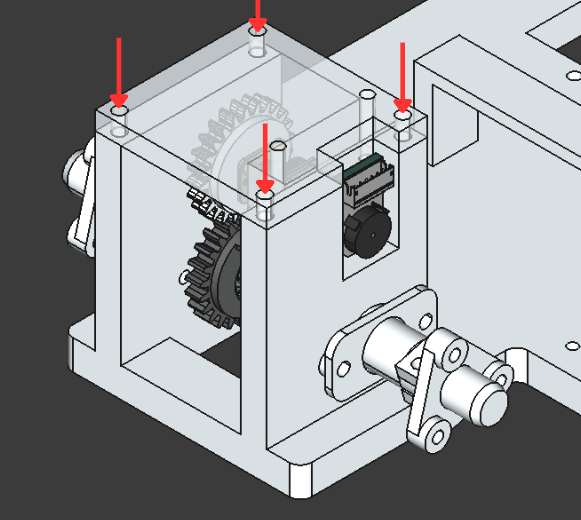
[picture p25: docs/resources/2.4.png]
   

1. Attach the wheels to the axles using 3x M3 screws on each side.

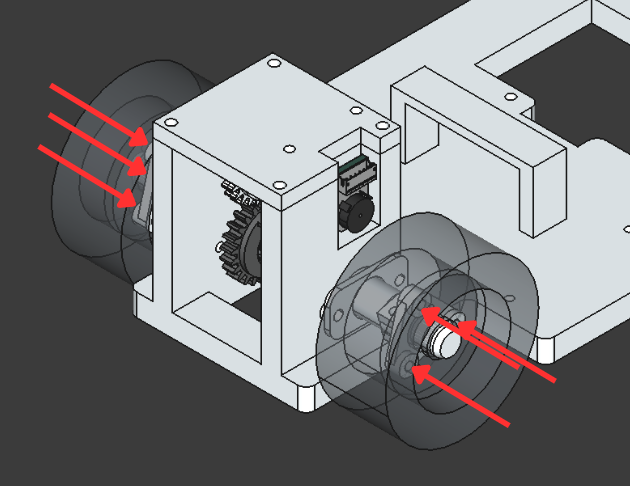
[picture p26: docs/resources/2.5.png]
   

**Step 3: Mount electronics**

1. Attach the camera to the front plate using 4x M2 screws, ensuring the wire is threaded through the small gap in the front plate.
   camview
1. Attach the UPS EP-0136 onto the Raspberry Pi 5, separated via 4x M2.5 standoffs, ensuring battery access at the bottom and the Raspberry Pi 5 facing upwards.
1. Attach the Raspberry Pi M.2 HAT+ to the Raspberry Pi 5 using M2.5 standoffs, and only connect using the ribbon cable.
1. Stick the Raspberry Pi Pico 2, BNO085 IMU, and the step-up module using tape on the back of the chassis.
1. Attach the LIDAR plate behind the Raspberry Pi, using 4x M2.5 standoffs and pillars to elevate the plate, ensuring the LIDAR is horizontal to the ground and has a 360-degree view around the robot by adjusting the standoffs.
1. Attach the button and RPLIDAR S2 onto the LIDAR Plate, ensuring the LIDAR sensor module is above the motor plate.
1. Organize the wiring for added components according to the [wiring diagram](#34-Circuit-Diagram)

> **The final result should look similar to this**
>
> stack
>
> *From top to bottom: Raspberry Pi M.2 HAT+, Raspberry Pi 5, UPS EP-0136*
>
> circuitunzoom
>
> *Figure: The component layout of the robot*

**Step 4: Upload the software**

1. Connect the Raspberry Pi 5 to your computer via SSH or a USB-C cable.
1. Follow the steps listed in [5.3](53-Compilation-/-Upload-Instructions).

> **Ensure all components are connected, and power on the robot**

<p align="right">
  <a href="#top">Back To Top</a>
</p>

## 9. Extras

[Setting Up a DHCP Server Using Ethernet Port with Internet Connection from Wireless LAN](other/dhcp-server-on-ethernet-port.md)

[How to Image Drive in Linux](other/image-drive-linux.md)

[Our Custom Randomiser Software](code/Future_Engineer_2025_Randomizer)

<p align="right">
  <a href="#top">Back To Top</a>
</p>

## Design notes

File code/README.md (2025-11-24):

# API Documentation

This section provides a complete overview of the software implemented in our self-driving robot system. This document contains a direct link to detailed documentations for every major hardware interface, processing pipeline, and communication layer between the Raspberry Pi 5 and Raspberry Pi Pico 2. Each directory below links to a dedicated README file describing the functionality, dependencies, and data flow within that module across all source code of the components.

### Table of contents

<!-- toc -->

- [Raspberry Pi 5](#raspberry-pi-5)
- [Raspberry Pi Pico 2](#raspberry-pi-pico-2)
- [Shared](#shared)

<!-- tocstop -->

## Raspberry Pi 5

The Raspberry Pi 5 serves as the primary processing unit of the system, responsible for high-level perception, computation, and communication. It handles sensor fusion from LiDAR and camera modules, performs navigation logic, and manages data exchange with the Pico 2 controller via I²C.

[**[CLICK HERE] Link to the API Documentation**](raspberry-pi-5/src/README.md)

## Raspberry Pi Pico 2

The Raspberry Pi Pico 2 acts as a low-level embedded controller dedicated to precise actuation and sensor interfacing. It governs real-time control loops, servo and motor operation, and communication with sensors like the BNO085 IMU through I²C and UART protocols.

[**[CLICK HERE] Link to the API Documentation**](raspberry-pi-pico-2/src/README.md)

## Shared

The Shared directory contains all cross-platform components used by both the Raspberry Pi 5 and Raspberry Pi Pico 2. These include common data structures, communication utilities, protocol definitions, and other foundational modules that standardize interactions across the entire system. By centralizing shared logic, this directory ensures consistent data handling, reduces duplication, and maintains interoperability between all subsystems.

[**[CLICK HERE] Link to the API Documentation**](shared/README.md)

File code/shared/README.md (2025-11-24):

# Shared Components (`shared/`)

This directory contains common definitions, constants, and fundamental data structures that are used across multiple primary components or subsystems in the project. The contents are organized into functional subdirectories.

______________________________________________________________________

## Subdirectories Overview

| Subdirectory | Description | Core Content | Detailed Reference |
| :--- | :--- | :--- | :--- |
| **`i2c`** | Definitions related to Inter-Integrated Circuit (I2C) communication protocols and memory addresses for hardware components. | `pico_i2c_mem_addr.h` | [i2c/README.md](i2c/README.md) |
| **`types`** | Fundamental, low-level data structure definitions, such as Inertial Measurement Unit (IMU) measurements. | `imu_struct.h` | [types/README.md](types/README.md) |

______________________________________________________________________

## Detailed Reference

### `shared/i2c`

This directory provides header files defining specific I2C memory maps and register addresses, commonly required when interacting with microcontrollers or peripheral hardware.

The primary file here is `pico_i2c_mem_addr.h`, which contains constants and definitions for the I2C interface on the Pico microcontroller.

### `shared/types`

This directory provides foundational structures that represent raw sensor data or common mathematical entities, essential for system operation.

The primary file here is `imu_struct.h`, which defines the structures used to hold raw or processed Inertial Measurement Unit data.

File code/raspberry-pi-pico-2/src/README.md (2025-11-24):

# Source Code (`src/`)

This directory contains the main application components, architectural layers, and foundational building blocks of the robot's operating system. It is organized into distinct directories based on functionality, promoting modularity and clear separation of concerns.

The root of this directory contains the primary entry point for the application.

______________________________________________________________________

## Architecture Overview

The codebase is logically organized into the following layers and core files:

| Directory/File | Layer Type | Purpose | API Reference Link |
| :--- | :--- | :--- | :--- |
| **`main.cpp`** | **Application Entry** | Contains the top-level application initialization, main execution loop, system startup logic, and coordination of data flow between the modules and processors. | N/A |
| **`modules`** | Hardware Interface | Contains high-level drivers and device managers that interact directly with the hardware (e.g., Camera, LIDAR, Pico). These components handle device communication and run dedicated background threads for data acquisition. | [modules/README.md](modules/README.md) |
| **`utils`** | Foundational | Contains reusable, domain-specific utilities like data logging, general-purpose algorithms (e.g., PID controllers), and foundational data structures. | [utils/README.md](utils/README.md) |
| **`shared`** | Cross-Cutting | Contains components that are shared across different execution platforms (Raspberry Pi 5 and Raspberry Pi Pico), such as common constants and header definitions. | [shared/README.md](shared/README.md) |

______________________________________________________________________

## Building

The build process for all components within `src/` is managed by the top-level project's CMake configuration, which recursively includes the `CMakeLists.txt` files found in the subdirectories.

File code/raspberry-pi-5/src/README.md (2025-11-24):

# Source Code (`src/`)

This directory contains the main application components, architectural layers, and foundational building blocks of the robot's operating system. It is organized into distinct directories based on functionality, promoting modularity and clear separation of concerns.

Each subdirectory contains specialized components and is managed by its own `README.md` file, which provides detailed documentation and API references.

______________________________________________________________________

## Architecture Overview

The codebase is logically organized into the following layers:

| Directory | Layer Type | Purpose | API Reference Link |
| :--- | :--- | :--- | :--- |
| **`types`** | Foundational | Defines all fundamental C++ structures (`structs`) used throughout the project for data exchange, ensuring consistent and type-safe interfaces between layers. | [types/README.md](types/README.md) |
| **`utils`** | Foundational | Contains reusable, domain-specific utilities like data logging, general-purpose algorithms (e.g., PID controllers, Ring Buffers), and geometric/directional concepts. | [utils/README.md](utils/README.md) |
| **`modules`** | Hardware Interface | Contains high-level drivers and device managers that interact directly with the hardware (e.g., Camera, LIDAR, Pico 2). These components handle device communication and run dedicated background threads for data acquisition. | [modules/README.md](modules/README.md) |
| **`processors`** | Core Logic | Contains algorithms for processing and fusing raw sensor data into meaningful environmental awareness, such as line extraction, object classification, and motion compensation. | [processors/README.md](processors/README.md) |
| **`shared`** | Cross-Cutting | Contains components that are shared across both Raspberry Pi 5 and Raspberry Pi Pico 2 (e.g., common constants, error handling patterns). | [shared/README.md](shared/README.md) |

______________________________________________________________________

## Building

The build process for all components within `src/` is managed by the top-level project's CMake configuration, which recursively includes the `CMakeLists.txt` files found in the subdirectories.

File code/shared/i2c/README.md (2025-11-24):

## `pico_i2c_mem_addr.h` Reference: Pico I2C Memory Map

This header defines the fixed memory map and addressing scheme used for I2C communication with the Pico microcontroller, allowing external devices to read sensor data and issue commands.

The Pico's shared I2C memory block has a total capacity of **256 bytes**.

______________________________________________________________________

### Global Constants and Sizes (`pico_i2c_mem_addr`)

| Constant | Value | Description |
| :--- | :--- | :--- |
| **`MEM_SIZE`** | $256$ | Total size of the shared I2C memory buffer (bytes). |
| **`COMMAND_SIZE`** | $1$ | Size of the Command register (1 byte). |
| **`STATUS_SIZE`** | $1$ | Size of the Status register (1 byte). |
| **`ACCEL_DATA_SIZE`** | `sizeof(ImuAccel)` | Size of the IMU acceleration data structure. |
| **`EULER_ANGLE_SIZE`** | `sizeof(ImuEuler)` | Size of the IMU Euler angle data structure. |
| **`IMU_DATA_SIZE`** | `ACCEL_DATA_SIZE + EULER_ANGLE_SIZE` | Total size of the combined IMU data payload. |
| **`ENCODER_ANGLE_SIZE`** | `sizeof(double)` | Size of the encoder angle data (typically 8 bytes). |
| **`MOVEMENT_INFO_SIZE`** | `sizeof(double) + sizeof(float)` | Total size for motor speed and steering percentage information. |

### Memory Addresses

The following addresses define the start point for reading or writing specific data blocks within the $256$-byte memory map.

| Address Constant | Address Value | Size (Bytes) | Content |
| :--- | :--- | :--- | :--- |
| **`COMMAND_ADDR`** | $0$ | $1$ | Write address for issuing commands (see `Command` enum). |
| **`STATUS_ADDR`** | $1$ | $1$ | Read address for the system status byte (see `StatusFlags` struct). |
| **`IMU_DATA_ADDR`** | $2$ | `IMU_DATA_SIZE` | Read address for combined IMU data (Accel + Euler). |
| **`ENCODER_ANGLE_ADDR`**| $2$ + `IMU_DATA_SIZE` | `ENCODER_ANGLE_SIZE` | Read address for the current encoder angle. |
| **`MOVEMENT_INFO_ADDR`**| $\\dots$ | `MOVEMENT_INFO_SIZE` | Read/Write address for current motor speed and steering targets. |

______________________________________________________________________

### Commands Namespace

The `pico_i2c_mem_addr::Command` namespace defines the available commands that can be written to the `COMMAND_ADDR` ($0$).

| Enum Value | Hex Value | Description |
| :--- | :--- | :--- |
| **`NO_COMMAND`** | `0x00` | Default state; no active command is being processed. |
| **`RESTART`** | `0x01` | Initiates a software restart of the Pico system. |
| **`CALIB_NO_OFFSET`** | `0x02` | Starts IMU calibration process without applying an offset correction. |
| **`CALIB_WITH_OFFSET`** | `0x03` | Starts IMU calibration process and calculates/applies offset correction. |
| **`SKIP_CALIB`** | `0x04` | Skips the automatic IMU calibration sequence on startup. |

______________________________________________________________________

### Status Flags

The `StatusFlags` structure represents the single status byte read from `STATUS_ADDR` ($1$). It uses bit-fields to pack multiple boolean states into one byte.

| Field | Bits | Description |
| :--- | :--- | :--- |
| **`is_running`** | $1$ | Bit 0: $1$ if the main system loop is active and running. |
| **`imu_ready`** | $1$ | Bit 1: $1$ if the IMU has been initialized and is ready to stream data. |
| **`reserved`** | $6$ | Bits 2-7: Reserved for future use. Always $0$. |

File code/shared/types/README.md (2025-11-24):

## `imu_struct.h` Reference: Inertial Measurement Unit (IMU) Data

This header defines fundamental structures used to represent raw sensor data derived from an Inertial Measurement Unit, specifically covering acceleration and orientation (Euler angles).

______________________________________________________________________

### Structure: `ImuAccel`

Represents the instantaneous acceleration measured along the three primary axes ($X, Y, Z$) of the sensor.

| Field | Type | Description |
| :--- | :--- | :--- |
| **`x`** | `float` | Acceleration along the X-axis (e.g., in $\\text{m}/\\text{s}^2$ or G-forces). |
| **`y`** | `float` | Acceleration along the Y-axis. |
| **`z`** | `float` | Acceleration along the Z-axis. |

______________________________________________________________________

### Structure: `ImuEuler`

Represents the orientation of the sensor in terms of Euler angles: Heading (Yaw), Roll, and Pitch.

| Field | Type | Description |
| :--- | :--- | :--- |
| **`h`** | `float` | **Heading (Yaw)**: Rotation around the vertical Z-axis. |
| **`r`** | `float` | **Roll**: Rotation around the longitudinal X-axis. |
| **`p`** | `float` | **Pitch**: Rotation around the lateral Y-axis. |

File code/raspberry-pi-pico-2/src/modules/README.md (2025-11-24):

# Modules (`modules/`)

This directory contains foundational hardware and communication interfaces, primarily designed for running on the embedded microcontroller (e.g., Raspberry Pi Pico) but also applicable to the main processor.

These components handle low-level device control, sensor data acquisition, and inter-process communication (IPC) through I2C.

______________________________________________________________________

## Components Overview

This directory is divided into sub-modules based on the hardware system or communication protocol they manage:

| Module Directory | Description | API Reference Link |
| :--- | :--- | :--- |
| **`controllers/bno085`** | **IMU Driver.** Provides a high-level wrapper for the BNO085 Inertial Measurement Unit (IMU), handling initialization, calibration, and continuous reading of fused orientation (Euler angles) and acceleration data. | [controllers/bno085/README.md](controllers/bno085/README.md) |
| **`controllers/motor`** | **Motor & Encoder Control.** Contains drivers for DC motors (`motor_controller.h`), quadrature encoders (`encoder_controller.h`), and the closed-loop PID-based speed regulator (`motor_speed_controller.h`). | [controllers/motor/README.md](controllers/motor/README.md) |
| **`controllers/servo`** | **Servo Control.** Provides precise PWM control for standard hobby RC servos, mapping angles to pulse widths using hardware PWM. | [controllers/servo/README.md](controllers/servo/README.md) |
| **`i2c_slave`** | **I2C Communication.** Implements the I2C Slave protocol, managing a shared memory buffer for inter-process communication between the microcontroller (Slave) and the main computer (Master). | [i2c_slave/README.md](i2c_slave/README.md) |

______________________________________________________________________

## Building

The build configuration for all modules is managed by the `CMakeLists.txt` files within the respective subdirectories.

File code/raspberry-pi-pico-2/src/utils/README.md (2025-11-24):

# Utilities (`utils/`)

This directory contains reusable, domain-specific utilities and foundational components used throughout the project, serving as common tools for various modules and processors.

Each subdirectory contains a component and its associated `README.md` file, providing detailed documentation, usage examples, and API references.

______________________________________________________________________

## Components Overview

Use the links below to navigate to the detailed documentation for each utility.

| Component Directory | Description | API Reference Link |
| :--- | :--- | :--- |
| **`pid_controller`** | A simple Proportional-Integral-Derivative (PID) controller class used for closed-loop control applications, such as motor speed or steering correction. | [pid_controller/README.md](pid_controller/README.md) |

______________________________________________________________________

## Building

The build configuration for all utilities is handled by the `CMakeLists.txt` file in this directory.

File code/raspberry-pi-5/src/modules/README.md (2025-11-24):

# Modules (`modules/`)

This directory contains high-level hardware interfaces and drivers designed to manage the robot's primary sensor and actuation systems. These modules encapsulate device initialization, multi-threading, data acquisition loops, and provide thread-safe access to sensor data.

All modules share a common pattern: they run a dedicated background thread to poll data and use a ring buffer to store recent samples, allowing the main application to consume data asynchronously.

______________________________________________________________________

## Components Overview

Use the links below to navigate to the detailed documentation for each hardware interface module.

| Module Directory | Description | API Reference Link |
| :--- | :--- | :--- |
| **`camera`** | Manages frame acquisition from the camera device in a background thread, providing thread-safe access to the latest video frames. | [camera/README.md](camera/README.md) |
| **`i2c_master`** | Provides the low-level I2C communication interface for the Raspberry Pi to interact with the Pico microcontrollers. | [i2c_master/README.md](i2c_master/README.md) |
| **`lidar`** | Initializes, controls, and acquires continuous scan data from the SLAMTEC LIDAR device in a separate scanning thread. | [lidar/README.md](lidar/README.md) |
| **`pico2`** | High-level interface to the Pico 2 microcontroller over I2C, handling continuous polling of IMU and encoder data, and transmitting motor control commands. | [pico2/README.md](pico2/README.md) |

______________________________________________________________________

## Building

The build configuration for all modules is handled by the `CMakeLists.txt` file in this directory.

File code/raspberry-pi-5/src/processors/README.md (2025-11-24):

# Processors (`processors/`)

This directory houses the core data processing and fusion algorithms responsible for interpreting raw sensor data into meaningful, actionable information about the robot's environment, such as object locations, wall segments, and path classification.

Each subdirectory contains a component and its associated `README.md` file, providing detailed documentation, usage examples, and API references.

______________________________________________________________________

## Components Overview

Use the links below to navigate to the detailed documentation for each processor component.

| Component Directory | Description | API Reference Link |
| :--- | :--- | :--- |
| **`camera`** | Handles visual processing, including color filtering in HSV space, contour detection, and calculating the horizontal angle of detected blocks. | [camera/README.md](camera/README.md) |
| **`lidar`** | Focuses on geometric processing of LIDAR scans, including line segment extraction, wall classification, and identifying traffic light clusters. | [lidar/README.md](lidar/README.md) |
| **`combined`** | Implements sensor fusion, synchronizing camera frames and LIDAR scans, combining visual (color) and spatial (position) data, and classifying detected objects relative to the robot's path. | [combined/README.md](combined/README.md) |

______________________________________________________________________

## Building

The build configuration for all processors is handled by the `CMakeLists.txt` file in this directory.

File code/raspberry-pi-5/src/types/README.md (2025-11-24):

# Core Data Structures (types/)

This directory houses the foundational C++ header files that define the primary data structures used across the entire robotics system. These structures typically contain sensor measurements, timestamps, and core state representations (e.g., pose, odometry).

## Structure Definitions Overview

| File | Primary Structures | Description |
| :---- | :---- | :---- |
| **camera_struct.h** | TimedFrame | Encapsulates an OpenCV image frame (cv::Mat) paired with a monotonic timestamp. |
| **lidar_struct.h** | RawLidarNode, TimedLidarData | Definitions for single LIDAR scan points and the full timestamped vector of a complete LIDAR sweep. |
| **pico2_struct.h** | TimedPico2Data | A combined sensor sample structure containing IMU (accelerometer/Euler angles) and encoder data. |
| **robot_pose_struct.h** | RobotDeltaPose | Defines a change in the robot's pose (delta X, delta Y, delta Heading) often calculated from odometry. |

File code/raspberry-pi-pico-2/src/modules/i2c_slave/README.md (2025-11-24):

## `i2c_slave.h` Reference: Inter-Process Communication (I2C Slave)

This header defines the communication interface and data exchange protocol for the I2C Slave device, typically implemented on a microcontroller like the Raspberry Pi Pico. It allows an I2C Master (e.g., a Raspberry Pi companion computer) to read sensor data (IMU, encoder) and write control commands to the microcontroller using an emulated shared memory architecture.

The core communication mechanism is a memory-mapped I2C buffer, where each address corresponds to a specific data point (e.g., motor speed, IMU yaw).

______________________________________________________________________

### Namespace: `i2c_slave`

#### Data Structures

| Struct Name | Description | Members |
| :--- | :--- | :--- |
| **`context_t`** | **I2C Memory Context.** Stores the entire shared memory block and tracks the state of the current I2C transaction, including the address the master is currently accessing. | `uint8_t mem[pico_i2c_mem_addr::MEM_SIZE]`: The shared memory buffer. <br> `uint8_t mem_address`: The register address pointer set by the master. <br> `bool mem_address_written`: Flag indicating if the master has set the memory address pointer. |
| **`context`** | **Global Instance.** The externally declared instance of `context_t` used by the I2C event handler to manage shared memory access. | N/A (Global variable) |

#### Core Initialization and Handling

| Function Signature | Description |
| :--- | :--- |
| **`void contextInit()`** | **Context Setup.** Resets the internal state of the `context` structure, clearing the memory buffer and state flags to prepare for transactions. |
| **`void i2cInit(i2c_inst_t *i2c, uint8_t slaveAddr, uint sdaPin, uint sclPin, uint baudrate)`** | **Hardware Initialization.** Initializes the physical I2C peripheral on the microcontroller, sets the slave address, configures the GPIO pins, and sets the communication baudrate. |
| **`void handler(i2c_inst_t *i2c, i2c_slave_event_t event)`** | **Event Handler.** This function is registered as the I2C interrupt handler. It processes all incoming I2C events (e.g., write-request, read-request, stop) and manages reads/writes to the `context.mem` buffer based on the current `mem_address`. |

#### Data Access Helpers

These functions provide thread-safe, high-level access to the memory-mapped data in the shared `context.mem` buffer, abstracting away the raw byte access and memory addressing details.

| Category | Function Signature | Description |
| :--- | :--- | :--- |
| **Command** | **`uint8_t getCommand()`** | Retrieves the latest control command sent by the master. |
| | **`void setCommand(uint8_t command)`** | Stores a new command byte in the I2C memory for the master to retrieve (primarily used for acknowledging commands). |
| **Status** | **`void setIsRunning(bool isRunning)`** | Sets the system's operational status flag. |
| | **`bool getIsRunning()`** | Retrieves the system's operational status flag. |
| | **`void setIsImuReady(bool ready)`** | Sets the status of the IMU sensor readiness. |
| | **`bool getIsImuReady()`** | Retrieves the status of the IMU sensor readiness. |
| **IMU Data** | **`void setImuData(const ImuAccel &accel, const ImuEuler &euler)`** | Writes the current `ImuAccel` and `ImuEuler` sensor readings into the memory buffer for the master to read. |
| | **`void getImuData(ImuAccel &outAccel, ImuEuler &outEuler)`** | Reads IMU data structures from the memory buffer (less common for the slave, but provided). |
| **Encoder** | **`void setEncoderAngle(double angle)`** | Writes the latest encoder angle (degrees or ticks) into the memory buffer. |
| | **`void getEncoderAngle(double &outAngle)`** | Reads the encoder angle from the memory buffer. |
| **Movement Info**| **`void setMovementInfo(double motorSpeed, float steeringPercent)`**| Writes the current measured motor speed (RPS) and steering output into the memory buffer. |
| | **`void getMovementInfo(double &outMotorSpeed, float &outSteeringPercent)`**| Reads the current motor speed and steering output from the memory buffer. |

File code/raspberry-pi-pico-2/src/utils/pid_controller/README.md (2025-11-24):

## `pid_controller.h` Reference: Simple PID Control

This header defines the `PIDController` class, a standard implementation of a Proportional-Integral-Derivative (PID) controller. This utility is used for closed-loop control systems to accurately maintain an output value (e.g., steering angle, motor speed) based on the error between a desired setpoint and a measured value.

______________________________________________________________________

### Class: `PIDController`

The PID controller calculates a control output $u(t)$ based on three terms:

1. **Proportional (P):** Responds to the current error, $e(t)$.
1. **Integral (I):** Responds to the accumulation of past errors, removing steady-state errors.
1. **Derivative (D):** Responds to the rate of change of the error, dampening oscillations.

$\\text{Output} = K_p e(t) + K_i \\int e(t) dt + K_d \\frac{d e(t)}{d t}$

#### Public Methods

| Method | Description | Parameters | Returns |
| :--- | :--- | :--- | :--- |
| **`PIDController(...)`** | **Constructor.** Initializes the controller gains and sets the output limits. | `Kp`, `Ki`, `Kd`: The respective gain constants. <br> `outputMin`: Minimum allowable output value (default: -100.0). <br> `outputMax`: Maximum allowable output value (default: 100.0). | N/A |
| **`double update(double error, double dt)`** | **Core Calculation.** Computes the new PID output based on the current system error and the time elapsed since the last call. Includes integral term accumulation and output clamping. | `error`: The difference between the setpoint and the measured value. <br> `dt`: The time step $\\Delta t$ in seconds since the last call to `update()`. | The computed and clamped PID output value. |
| **`void reset()`** | **State Reset.** Clears the accumulated integral sum (`integral_`) and the previous error (`lastError_`) to reset the controller state. | N/A | N/A |

#### Private Members (Internal State)

| Member | Type | Description |
| :--- | :--- | :--- |
| **`Kp_`, `Ki_`, `Kd_`** | `double` | The proportional, integral, and derivative gain constants. |
| **`integral_`** | `double` | The accumulated sum of errors multiplied by $dt$, used for the integral term. |
| **`lastError_`** | `double` | The error value from the previous `update()` call, used to calculate the derivative term. |
| **`outputMin_`, `outputMax_`** | `double` | The bounds used to clamp the final output value. |

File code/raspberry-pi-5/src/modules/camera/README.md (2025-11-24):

## `CameraModule.h` Reference: Threaded Camera Capture Module

This header defines the `CameraModule` class, which manages capturing image frames in a dedicated background thread, providing thread-safe access to the latest frames and optional binary logging.

______________________________________________________________________

### Class: `CameraModule`

| Feature | Description |
| :--- | :--- |
| **Capture Source** | Uses the `lccv::PiCamera` class to interface with the camera device. |
| **Threaded Operation** | Runs a background thread (`captureLoop`) to continuously grab frames. |
| **Data Buffer** | Stores recent frames in a `RingBuffer<TimedFrame>` for history and asynchronous access. |
| **Thread Safety** | Uses a `std::mutex` for safe buffer access and a `std::condition_variable` for blocking waits. |

#### Public Type

| Type | Description |
| :--- | :--- |
| **`CameraOptionCallback`** | `std::function<void(lccv::PiCamera &)>`. A functional type used to pass custom configuration settings to the internal `lccv::PiCamera` instance during initialization or runtime. |

#### Public Methods

| Method | Description |
| :--- | :--- |
| **`CameraModule(CameraOptionCallback callback)`** | **Constructor (No Logging).** Initializes the module and configures the camera. Does not start the capture thread. |
| **`CameraModule(Logger *logger, CameraOptionCallback callback)`** | **Constructor (With Logging).** Initializes the module, configures the camera, and stores the provided pointer to an external `Logger` instance. |
| **`~CameraModule()`** | **Destructor.** Safely calls `stop()` to ensure the capture thread is stopped and joined. |
| **`void changeSetting(CameraOptionCallback callback)`** | Applies a new configuration to the internal camera instance, allowing dynamic changes (e.g., resolution, exposure). |
| **`bool start()`** | Starts the dedicated background thread that executes the frame capture loop. Returns `true` on success. |
| **`void stop()`** | Stops the capture loop, signals the thread to exit, and blocks until the thread has finished execution (`join`). |
| **`bool getFrame(TimedFrame &outTimedFrame) const`** | **Non-blocking read.** Retrieves the most recently captured `TimedFrame` (image and timestamp) from the internal buffer. Returns `true` if a frame is available. |
| **`size_t bufferSize() const`** | Returns the current number of frames stored in the internal `RingBuffer`. |
| **`bool getAllTimedFrame(std::vector<TimedFrame> &outTimedFrames) const`** | Retrieves **all** frames currently in the buffer, ordered from oldest to newest. Returns `true` if the buffer is non-empty. |
| **`bool waitForFrame(TimedFrame &outTimedFrame)`** | **Blocking read.** Suspends the calling thread until a new frame is captured, utilizing the condition variable to notify of new data. |
| **`void startLogging()`** | Enables binary logging of all subsequently captured frames to the configured `Logger` instance. |
| **`void stopLogging()`** | Disables binary logging of captured frames. |

#### Private Members (Internal State)

| Member | Type | Description |
| :--- | :--- | :--- |
| **`captureLoop()`** | `void` | Background thread function responsible for continuous capture, buffering, signaling, and optional logging. |
| **`cam_`** | `lccv::PiCamera` | The underlying camera interface instance. |
| **`cameraThread_`** | `std::thread` | The background thread running the capture loop. |
| **`running_`** | `std::atomic<bool>` | Atomic flag controlling the execution state of the capture loop. |
| **`frameMutex_`** | `std::mutex` | Mutex protecting access to the `frameBuffer_` and condition variable. |
| **`frameUpdated_`** | `std::condition_variable` | Used to notify waiting threads (e.g., in `waitForFrame`) whenever a new frame is captured. |
| **`frameBuffer_`** | `RingBuffer<TimedFrame>` | Circular buffer that stores the last $30$ captured frames and their timestamps. |
| **`logger_`** | `Logger*` | Pointer to the system logger instance. |
| **`logging_`** | `bool` | Flag indicating if frame data is currently being logged. |

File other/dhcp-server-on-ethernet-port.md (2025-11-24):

# Setting Up a DHCP Server Using Ethernet Port with Internet Connection from Wireless LAN

This guide will show you how to set up your laptop or computer's ethernet port to act as a DHCP server, providing IP addresses and internet access to a connected device through the ethernet interface, while the laptop receives its internet connection via wireless LAN.

> **Tested on Ubuntu and Fedora.**\
> On Fedora, the package names and service commands differ slightly — see the [Fedora Notes](#fedora-notes) section at the end.

______________________________________________________________________

## Step 1: Install Required Packages

Before starting, ensure you have `isc-dhcp-server` and `iptables` installed. You can install them by running:

### Ubuntu/Debian:

```bash
sudo apt update
sudo apt install isc-dhcp-server iptables-persistent
```

### Fedora:

```bash
sudo dnf install dhcp-server iptables-services
```

______________________________________________________________________

## Step 2: How to Find `YOUR_ETHERNET_INTERFACE` and `YOUR_WIRELESS_INTERFACE`:

To find the name of your interfaces, run the following command:

```bash
ip a
```

Look for the interface name associated with your ethernet connection (it could be something like `enp3s0`, `enp3s0f0`, etc.). Replace all `YOUR_ETHERNET_INTERFACE` in later steps with the name of your ethernet interface.

Then find the name of your wireless interface (it might be `wlp1s0`, `wlan0`, or something similar). Replace all `YOUR_WIRELESS_INTERFACE` in later steps with the name of your wireless interface.

______________________________________________________________________

## Step 3: Configure DHCP Server

### 3.1 Edit DHCP Server Configuration

First, configure the DHCP server to listen on your ethernet interface. Run the following command to edit the DHCP server configuration:

#### Ubuntu:

```bash
sudo nano /etc/default/isc-dhcp-server
```

Modify the file to look like this:

```bash
INTERFACESv4="YOUR_ETHERNET_INTERFACE"
INTERFACESv6=""
```

#### Fedora:

Don't need to do anything.

______________________________________________________________________

### 3.2 Define IP Range and Subnet in DHCP Config

Next, define the IP range and subnet to be used by the DHCP server:

```bash
sudo nano /etc/dhcp/dhcpd.conf
```

Add the following configuration:

```bash
subnet 192.168.39.0 netmask 255.255.255.0 {
  range 192.168.39.10 192.168.39.50;
  option subnet-mask 255.255.255.0;
  option routers 192.168.39.1;
}
```

This configuration will provide IP addresses in the range of `192.168.39.10` to `192.168.39.50`.

______________________________________________________________________

## Step 4: Configure Ethernet Interface for Static IP

### 4.1 Add a New Network Connection

Now, you need to add a static IP address to your ethernet interface and configure it to use the DHCP server. Run the following `nmcli` command:

```bash
nmcli connection add type ethernet con-name "DHCP Server" ifname YOUR_ETHERNET_INTERFACE autoconnect yes \
  connection.autoconnect-priority 0 ipv4.method manual ipv4.addresses 192.168.39.1/24 \
  ipv4.route-metric -1 ipv4.may-fail yes ipv4.dhcp-send-hostname yes ipv6.method disabled
```

Replace `YOUR_ETHERNET_INTERFACE` with the interface name you found earlier.

This assigns the IP `192.168.39.1` to the ethernet interface.

______________________________________________________________________

## Step 5: Enable IP Forwarding

### 5.1 Enable IP Forwarding in `sysctl.conf`

#### Ubuntu:

To forward internet traffic from your wireless LAN to the ethernet interface, enable IP forwarding by running:

```bash
sudo nano /etc/sysctl.conf
```

Uncomment the line that enables IP forwarding:

```bash
#net.ipv4.ip_forward=1
```

Remove the `#` so it becomes:

```bash
net.ipv4.ip_forward=1
```

#### Fedora:

On Fedora, the recommended way is to create a custom config file:

```bash
echo "net.ipv4.ip_forward=1" | sudo tee /etc/sysctl.d/99-ipforward.conf
```

### 5.2 Apply Changes

#### Ubuntu:

Apply the changes to the system settings:

```bash
sudo sysctl -p
```

#### Fedora:

Apply the changes to the system settings:

```bash
sudo sysctl --system
```

______________________________________________________________________

## Step 6: Set Up IP Masquerading

### 6.1 Configure iptables for NAT

Now, use `iptables` to configure Network Address Translation (NAT) so the connected device can use the internet from your wireless connection. Run the following commands:

```bash
sudo iptables -t nat -A POSTROUTING -o YOUR_WIRELESS_INTERFACE -j MASQUERADE
sudo iptables -A FORWARD -i YOUR_ETHERNET_INTERFACE -o YOUR_WIRELESS_INTERFACE -j ACCEPT
sudo iptables -A FORWARD -i YOUR_WIRELESS_INTERFACE -o YOUR_ETHERNET_INTERFACE -m state --state RELATED,ESTABLISHED -j ACCEPT
```

For `YOUR_ETHERNET_INTERFACE` and `YOUR_WIRELESS_INTERFACE`, use the interface names you found earlier.

______________________________________________________________________

### 6.2 Save iptables Rules

#### Ubuntu:

```bash
sudo netfilter-persistent save
```

#### Fedora:

```bash
sudo service iptables save
sudo systemctl enable iptables
sudo systemctl start iptables
```

______________________________________________________________________

## Step 7: Restart Services

### 7.1 Restart DHCP Server

#### Ubuntu:

```bash
sudo systemctl restart isc-dhcp-server
```

#### Fedora:

```bash
sudo systemctl restart dhcpd
```

Your laptop's ethernet port is now acting as a DHCP server, providing IP addresses to connected devices and routing internet traffic from your wireless LAN.

______________________________________________________________________

## Fedora Notes

- Fedora uses **`dhcpd`** instead of `isc-dhcp-server`.
- Configuration files are in:
  - `/etc/sysconfig/dhcpd`
  - `/etc/dhcp/dhcpd.conf`
- Service name: `dhcpd`
- iptables rules are managed via `iptables-services`.
- If `.local` hostnames (like `rpi5.local`) stop resolving after switching from Wi-Fi to Ethernet, restart Avahi:
  ```bash
  sudo systemctl restart avahi-daemon
  ```
  or force rescan:
  ```bash
  sudo avahi-daemon --kill && sudo avahi-daemon --daemonize
  ```

______________________________________________________________________

## Additional Tip: Prevent Ethernet Power-Down on Battery

If you notice that the ethernet interface (e.g., `enp3s0f0`) doesn't wake up properly when reconnecting the cable, especially on battery power, it may be due to power management putting the NIC into a low-power state.

You can apply this temporary fix to force it to stay on:

```bash
echo on | sudo tee /sys/class/net/YOUR_ETHERNET_INTERFACE/device/power/control
```

This disables the power-saving mode for that ethernet device until the next reboot. Replace `YOUR_ETHERNET_INTERFACE` with your actual ethernet interface.

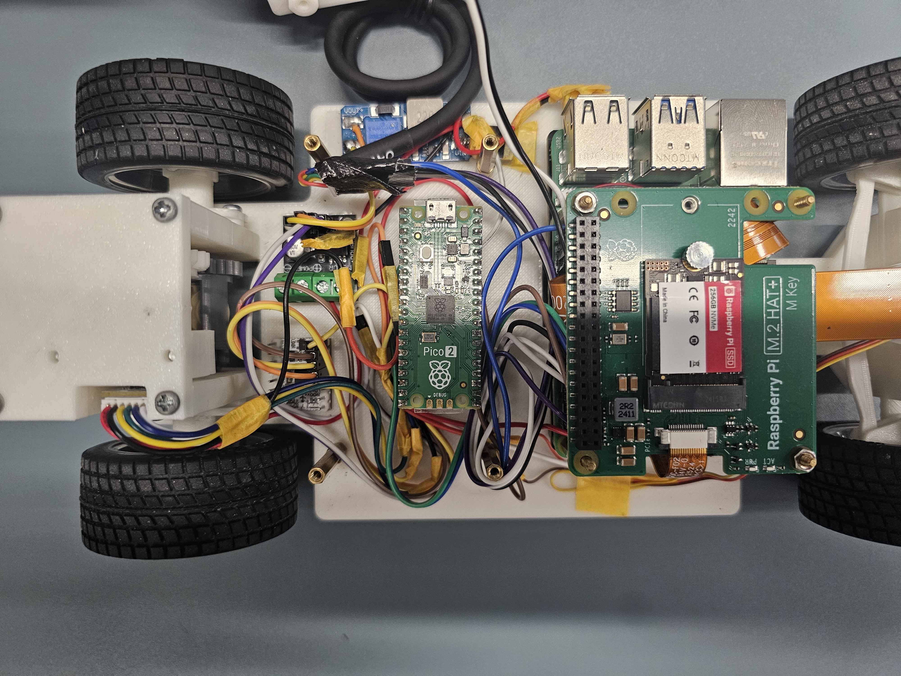
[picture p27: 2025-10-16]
docs/resources/circuitzoom.jpg

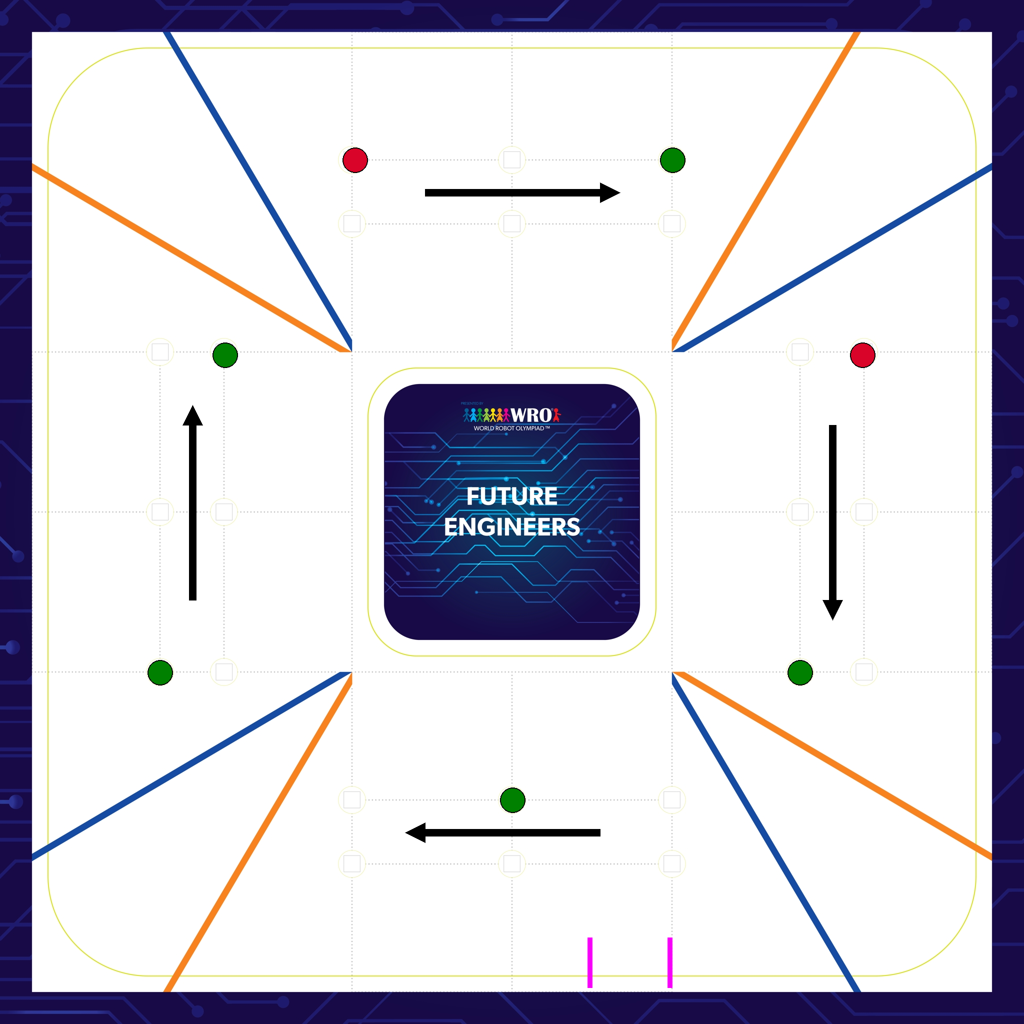
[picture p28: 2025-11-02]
docs/resources/WRO_Obstacle_Challenge_Layout2.png

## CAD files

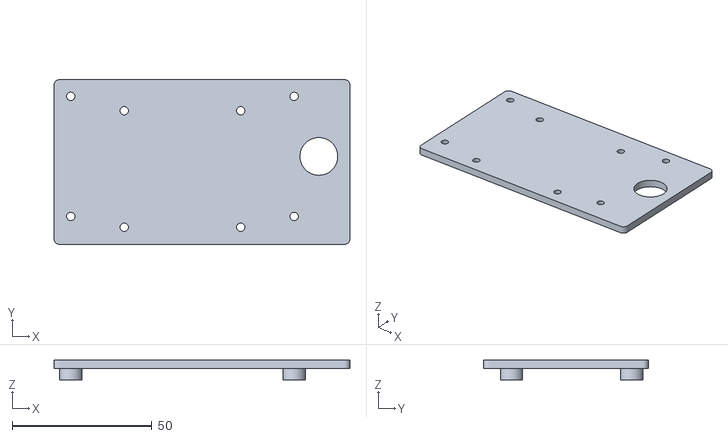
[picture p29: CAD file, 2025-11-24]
FreeCAD-Files/Assembly/mesh_export/LidarPlate_1x.stl
106.0 x 59.0 x 7.00

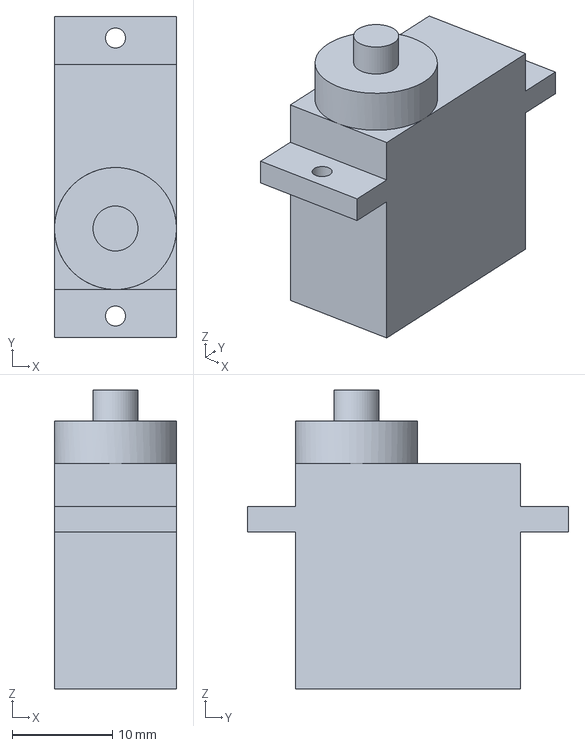
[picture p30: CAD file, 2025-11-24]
FreeCAD-Files/Parts/S0004m.FCStd
12.2 x 32.1 x 29.9 mm

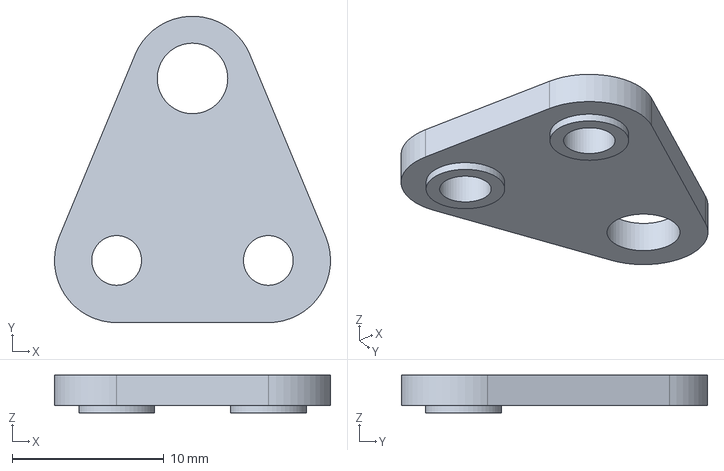
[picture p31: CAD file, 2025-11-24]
FreeCAD-Files/Parts/TBoneLinkage/TBoneLinkageTop.FCStd
18.2 x 20.2 x 2.50 mm

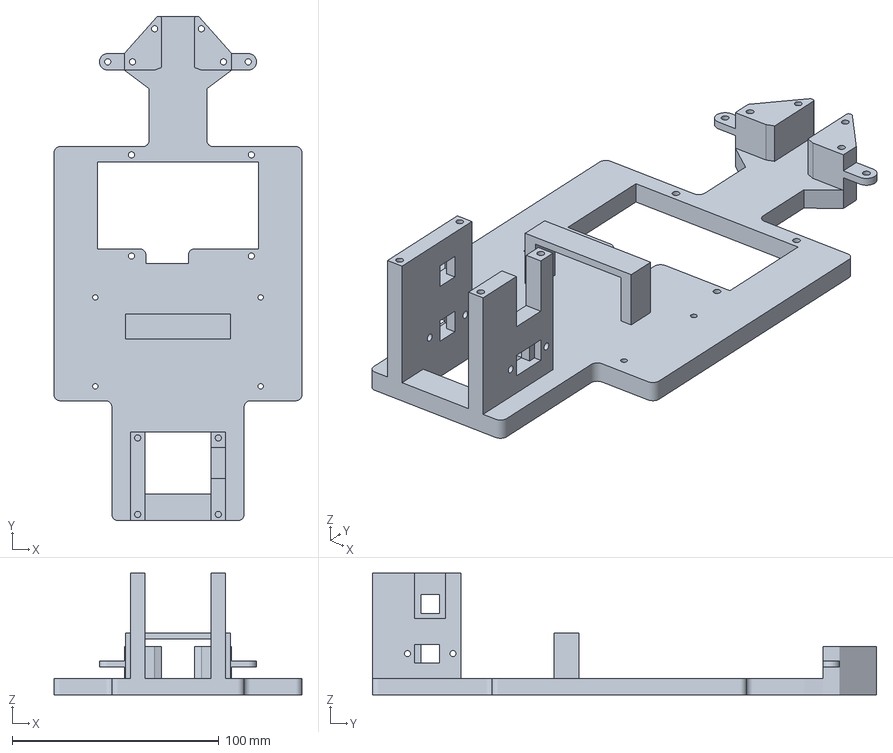
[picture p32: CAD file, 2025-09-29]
Slicer-Files/Bambu_Lab_P1S_(Bambu_Slicer)/Chassis_1x.3mf
120.0 x 244.0 x 59.0 mm

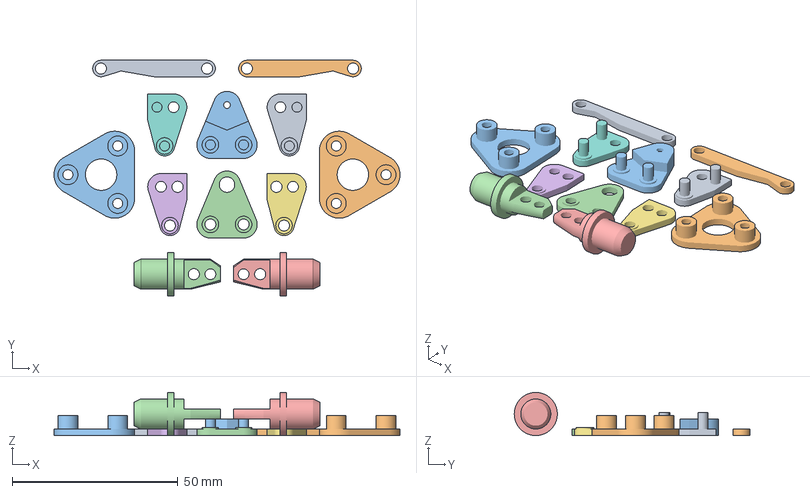
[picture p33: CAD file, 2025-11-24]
Slicer-Files/Ender_3_V3_KE_(Cura_Slicer)/CE3V3KE_Linkages.3mf
104.3 x 71.0 x 13.0 mm
TransferLinkageLeft_1x.stl
TransferLinkageRight_1x.stl
TBoneLinkageBottom_1x.stl
FrontWheelAxleLeft_1x.stl
FrontWheelAxleRight_1x.stl
WheelLinkageTopLeft_1x.stl
WheelLinkageTopRight_1x.stl
WheelLinkageBottomLeft_1x.stl
WheelLinkageBottomRight_1x.stl
FrontWheelStopper_2x.stl
FrontWheelStopper_2x.stl(1)
TBoneLinkageTop_1x.stl

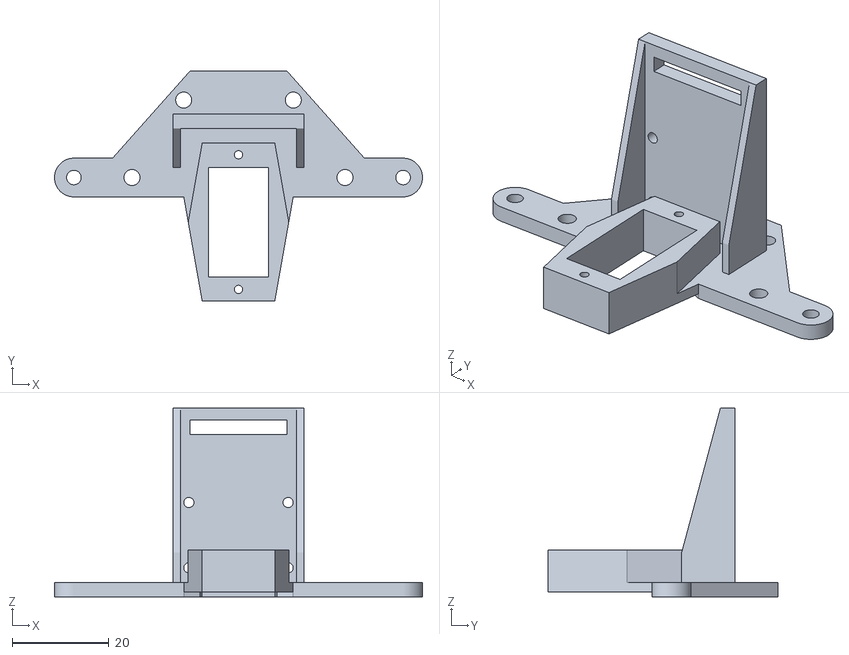
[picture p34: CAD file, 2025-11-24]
FreeCAD-Files/Assembly/mesh_export/FrontCover_1x.stl
76.0 x 47.5 x 39.0

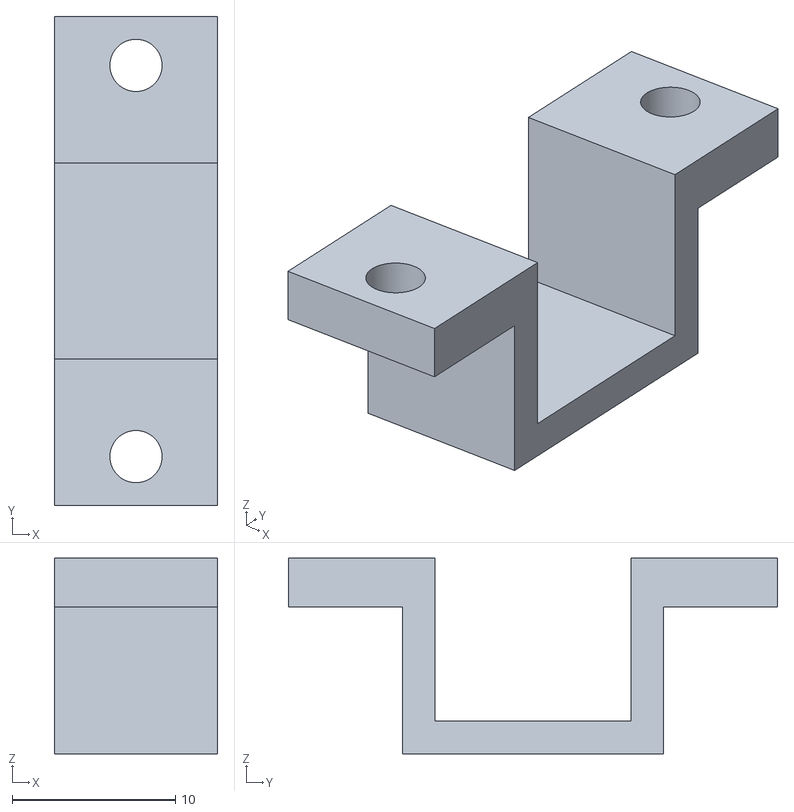
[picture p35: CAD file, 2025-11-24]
FreeCAD-Files/Assembly/mesh_export/MotorHolder_1x.stl
10.00 x 30.0 x 12.0

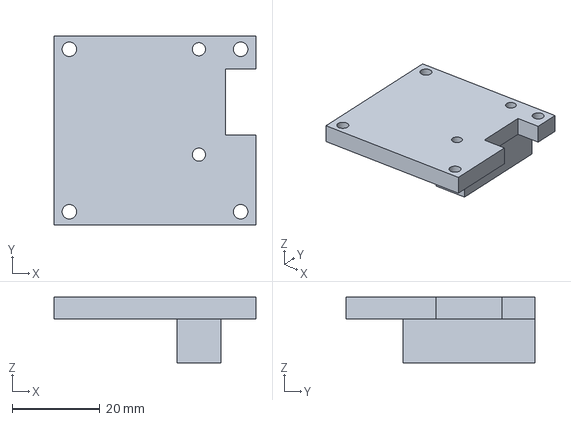
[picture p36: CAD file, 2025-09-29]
FreeCAD-Files/Parts/MotorPlate.FCStd
46.0 x 43.0 x 15.0 mm

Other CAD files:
FreeCAD-Files/Assembly/FrontAssembly.FCStd
FreeCAD-Files/Assembly/MainAssembly.FCStd
FreeCAD-Files/Parts/FrontCover.FCStd
Slicer-Files/Ender_3_V3_KE_(Cura_Slicer)/CE3V3KE_FrontCover_1x.3mf
FreeCAD-Files/Parts/MotorHolder.FCStd
Slicer-Files/Ender_3_V3_KE_(Cura_Slicer)/CE3V3KE_LidarPlate_1x.3mf
FreeCAD-Files/Assembly/mesh_export/TBoneLinkageTop_1x.stl
FreeCAD-Files/Parts/Chassis.FCStd
FreeCAD-Files/Assembly/mesh_export/Chassis_1x.stl
FreeCAD-Files/Parts/LidarPlate.FCStd

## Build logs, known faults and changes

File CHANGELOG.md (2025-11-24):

# Changelog

## [0.2.1](https://github.com/Chayanon-Ninyawee/KMIDS-GFM-Future-Engineer-2025/compare/v0.2.0...v0.2.1) (2025-11-24)

### Bug Fixes

* Fix camera HFOV value ([a07019a](https://github.com/Chayanon-Ninyawee/KMIDS-GFM-Future-Engineer-2025/commit/a07019a5bdc556d9cc0608c75cf16289d5e02873))

## [0.2.0](https://github.com/Chayanon-Ninyawee/KMIDS-GFM-Future-Engineer-2025/compare/v0.1.6...v0.2.0) (2025-11-24)

### Features

* Add log_to_video ([6b4a561](https://github.com/Chayanon-Ninyawee/KMIDS-GFM-Future-Engineer-2025/commit/6b4a561095f6ad7b2c5020074f32a4223e50c1c3))
* Add randomizer ([6a730c6](https://github.com/Chayanon-Ninyawee/KMIDS-GFM-Future-Engineer-2025/commit/6a730c68042de092d1243c262ceffc361d50ad19))
* Add unparking ([0725b79](https://github.com/Chayanon-Ninyawee/KMIDS-GFM-Future-Engineer-2025/commit/0725b79c82d1b0e86e216618f0d4b9f667f311aa))
* Change pico2 code to match to new servo ([16d0cbf](https://github.com/Chayanon-Ninyawee/KMIDS-GFM-Future-Engineer-2025/commit/16d0cbf4d19d62a0ead5e200f94077c2bd1952a9))
* Change servo to S0009m ([f1f7d38](https://github.com/Chayanon-Ninyawee/KMIDS-GFM-Future-Engineer-2025/commit/f1f7d38cc288a3885c62ada8f46330f9c00fb5ea))
* Make obstacle_challenge know turn direction when start in the parking lot ([357e9ea](https://github.com/Chayanon-Ninyawee/KMIDS-GFM-Future-Engineer-2025/commit/357e9ea3be3eadd908b0683bcdb12e1ec62996ae))
* Make the robot Push when it know all the traffic light ([e6ebc04](https://github.com/Chayanon-Ninyawee/KMIDS-GFM-Future-Engineer-2025/commit/e6ebc04457d14d01e730fa49f284b337adaca4c0))
* Re-slice the FrontCover ([1b9133b](https://github.com/Chayanon-Ninyawee/KMIDS-GFM-Future-Engineer-2025/commit/1b9133becd7ba550b13069e33e0a839d672cad08))
* Re-slice the Linkages ([c59011c](https://github.com/Chayanon-Ninyawee/KMIDS-GFM-Future-Engineer-2025/commit/c59011c5b1d0a00ed8f390af8c047f892694d2d8))

### Bug Fixes

* Check for delta pose error ([5330650](https://github.com/Chayanon-Ninyawee/KMIDS-GFM-Future-Engineer-2025/commit/5330650c2bac4897c8f94c2da23384ac4ac9cba7))
* Fix camera see parking wall as red and associate that to the traffic light ([31b4a19](https://github.com/Chayanon-Ninyawee/KMIDS-GFM-Future-Engineer-2025/commit/31b4a197741e015ba6914639b46747f7721ee104))
* Fix CCW parking ([53957f9](https://github.com/Chayanon-Ninyawee/KMIDS-GFM-Future-Engineer-2025/commit/53957f9bcf40376ac5299809e56d2b4ef2bdafd3))
* Fix logger issue ([4a7a8f7](https://github.com/Chayanon-Ninyawee/KMIDS-GFM-Future-Engineer-2025/commit/4a7a8f780bffa5e4a9756a679c043f2df5bd74e7))
* Fix obstacle_challenge backward pid ([8f61485](https://github.com/Chayanon-Ninyawee/KMIDS-GFM-Future-Engineer-2025/commit/8f6148572d78b3e689b6c7a4e2ac5a3ec5a92f35))
* Fix obstacle_challenge heading diff calculation ([59ece05](https://github.com/Chayanon-Ninyawee/KMIDS-GFM-Future-Engineer-2025/commit/59ece05e22e3a91ab1b4b5c5e59ee7faab672b8d))
* Fix obstacle_challenge traffic light detection issue ([822ae8d](https://github.com/Chayanon-Ninyawee/KMIDS-GFM-Future-Engineer-2025/commit/822ae8d92e3adeb365331d99c43e910c62df9d45))
* Fix open_challenge backward pid ([ad4ab77](https://github.com/Chayanon-Ninyawee/KMIDS-GFM-Future-Engineer-2025/commit/ad4ab776eec2c03cf4b5d303ee30ff24bbfea90a))
* Fix scan map ([979dbdc](https://github.com/Chayanon-Ninyawee/KMIDS-GFM-Future-Engineer-2025/commit/979dbdc6edc2410714c98800b33f26083ca9267b))
* Fix traffic light detection issue and CW parking ([bb7ca82](https://github.com/Chayanon-Ninyawee/KMIDS-GFM-Future-Engineer-2025/commit/bb7ca826213d53da3c94902d144f89272ddb8b65))
* Make build-arm64.sh not fail when failed to pull docker image ([f96658f](https://github.com/Chayanon-Ninyawee/KMIDS-GFM-Future-Engineer-2025/commit/f96658fd7f5915079d58323516af78aefde8a33d))
* Make CW Unpark better ([b077179](https://github.com/Chayanon-Ninyawee/KMIDS-GFM-Future-Engineer-2025/commit/b0771793c444d3054422d6c8172822dae9b82bd6))
* Make LidarModule read lidar healy error code when timed out 3 times in a row ([3417f34](https://github.com/Chayanon-Ninyawee/KMIDS-GFM-Future-Engineer-2025/commit/3417f347b1b6e0ee9102a7c6252a963487a01eac))
* Make obstacle_challenge more stable ([74c1493](https://github.com/Chayanon-Ninyawee/KMIDS-GFM-Future-Engineer-2025/commit/74c1493735c5ca68ac901cb45c6d8ac3cf9dd865))
* Make pushing lap not check for traffic lights ([4b23905](https://github.com/Chayanon-Ninyawee/KMIDS-GFM-Future-Engineer-2025/commit/4b2390551d9ec13fef30b19eed61634a1441ed9f))
* Move lidarData filtering to the correct place ([0bf1d07](https://github.com/Chayanon-Ninyawee/KMIDS-GFM-Future-Engineer-2025/commit/0bf1d0765e10f61500a1543a9d81b361e62e9460))
* Start camera logging in obstacle_challenge ([59fedce](https://github.com/Chayanon-Ninyawee/KMIDS-GFM-Future-Engineer-2025/commit/59fedce9350e9707633f02d97b2356babf8372b1))

### Refactor

* Encapsulate open challenge state machine ([05d75f8](https://github.com/Chayanon-Ninyawee/KMIDS-GFM-Future-Engineer-2025/commit/05d75f8058d8dca053d82276666b21deffb0ff11))
* Refactor obstacle challenge ([e7225c5](https://github.com/Chayanon-Ninyawee/KMIDS-GFM-Future-Engineer-2025/commit/e7225c5e963644ec276be748eca567356a781b5d))
* Refactor open_challenge ([6f74596](https://github.com/Chayanon-Ninyawee/KMIDS-GFM-Future-Engineer-2025/commit/6f745961222d80291d9b3c37eef66697b76ee7e0))
* Rename open challenge mode naming ([9a4abbc](https://github.com/Chayanon-Ninyawee/KMIDS-GFM-Future-Engineer-2025/commit/9a4abbcc32818041515d9b42266b48b9d9078ebf))

### Miscellaneous Tasks

* Add QOL scripts ([4e07993](https://github.com/Chayanon-Ninyawee/KMIDS-GFM-Future-Engineer-2025/commit/4e0799357786b23a55872766809364f04e7f347f))

## [0.1.6](https://github.com/Chayanon-Ninyawee/KMIDS-GFM-Future-Engineer-2025/compare/v0.1.5...v0.1.6) (2025-11-07)

### Documentation

* Add BNO085 draft and fix slicer file and gcode confusion in file section ([4c4d662](https://github.com/Chayanon-Ninyawee/KMIDS-GFM-Future-Engineer-2025/commit/4c4d6622ca5488f35872bca271dd6d6bb5fafedb))
* Add BNO085 specs table and subsection 7 ([b48f3f0](https://github.com/Chayanon-Ninyawee/KMIDS-GFM-Future-Engineer-2025/commit/b48f3f0ce3d0a5251d49c8dd1d988712401f8835))
* Add brief title to each API README ([90b8f3f](https://github.com/Chayanon-Ninyawee/KMIDS-GFM-Future-Engineer-2025/commit/90b8f3f6eeff70e76419473a00766c04f28a2425))
* Add chassis pic and dimensions ([024cf1c](https://github.com/Chayanon-Ninyawee/KMIDS-GFM-Future-Engineer-2025/commit/024cf1cebe980d25ee212ab159115c0c9b36a7c5))
* Add component pics to building instructions ([5f244fd](https://github.com/Chayanon-Ninyawee/KMIDS-GFM-Future-Engineer-2025/commit/5f244fd3ad5ea660c3f5b182fe43a25e9fe5f166))
* Add differential gear section to 2.1 ([befae24](https://github.com/Chayanon-Ninyawee/KMIDS-GFM-Future-Engineer-2025/commit/befae249a6f3cdecdba06aff27e93b0963555701))
* Add M.2 HAT+ to power and sense management draft ([8db13ec](https://github.com/Chayanon-Ninyawee/KMIDS-GFM-Future-Engineer-2025/commit/8db13ec84c6227d023151df619b59447026bd9a8))
* Add new component pics ([67496df](https://github.com/Chayanon-Ninyawee/KMIDS-GFM-Future-Engineer-2025/commit/67496dfa1a8866086de51dd00d8b7ec8e6819aa6))
* Add numbering for subsection 7 and clarify 7.1 ([8265d35](https://github.com/Chayanon-Ninyawee/KMIDS-GFM-Future-Engineer-2025/commit/8265d356ecb567008f7523dddb25e3daa5d804f8))
* Add placeholder section for transistor and motor driver ([5ab1097](https://github.com/Chayanon-Ninyawee/KMIDS-GFM-Future-Engineer-2025/commit/5ab1097b746f60841f25d0dd16c08a18bf0e161d))
* Add power consumption section draft ([0f9771b](https://github.com/Chayanon-Ninyawee/KMIDS-GFM-Future-Engineer-2025/commit/0f9771b6c54959a85b4f68066b3027bf678a2a9f))
* Add randomiser files for documentation ([53b00e5](https://github.com/Chayanon-Ninyawee/KMIDS-GFM-Future-Engineer-2025/commit/53b00e56003cd1a266f6c9afccd81c7da809bfc6))
* Add README.md to folders ([612838c](https://github.com/Chayanon-Ninyawee/KMIDS-GFM-Future-Engineer-2025/commit/612838cbd905c44cb6e2583a29700142d096d6ed))
* Add small description paragraphs for processing units ([25f8b91](https://github.com/Chayanon-Ninyawee/KMIDS-GFM-Future-Engineer-2025/commit/25f8b91e8418673698076f7b50e2d9aee71e404c))
* Align the back to top button to the right ([8b83cf8](https://github.com/Chayanon-Ninyawee/KMIDS-GFM-Future-Engineer-2025/commit/8b83cf8e0cf27cea0d3bbd13d7cc783e4f0278a1))
* Change all path using backslash to forward slash ([836bda2](https://github.com/Chayanon-Ninyawee/KMIDS-GFM-Future-Engineer-2025/commit/836bda26ac1b0c51a56dbf3b3f2eea9e70900d9c))
* Change and add robot pics ([22e02fa](https://github.com/Chayanon-Ninyawee/KMIDS-GFM-Future-Engineer-2025/commit/22e02fa41a1483bbefaf73e9e5a2e1482257688c))
* Change LIDAR pic ([2f54820](https://github.com/Chayanon-Ninyawee/KMIDS-GFM-Future-Engineer-2025/commit/2f5482084c6b5ae7aac7ab9d56dc9b6b19e51797))
* Change servo from S0004M to S0009M ([a0745da](https://github.com/Chayanon-Ninyawee/KMIDS-GFM-Future-Engineer-2025/commit/a0745da8e1834c1109b09d050d039f681cbb1539))
* Change specs of LIDAR and specify component type ([5eef613](https://github.com/Chayanon-Ninyawee/KMIDS-GFM-Future-Engineer-2025/commit/5eef613f3ac4cdf3b8f5d265641dcc214ce2cc7a))
* Change wording structure of the steering section ([6fd49a4](https://github.com/Chayanon-Ninyawee/KMIDS-GFM-Future-Engineer-2025/commit/6fd49a4a60d9d3c1625070d38b844ad0ebeafe1d))
* Clean up documentation for typo and wording consistency ([cb82a95](https://github.com/Chayanon-Ninyawee/KMIDS-GFM-Future-Engineer-2025/commit/cb82a95750bb44a2431bd87e2e41d787b252a021))
* Finalise BNO085 details and Section 9 ([b254871](https://github.com/Chayanon-Ninyawee/KMIDS-GFM-Future-Engineer-2025/commit/b2548710b1aedf32e92ab364a10535dd5392ebd4))
* Improve readability of the API Documentation landing page ([85d791c](https://github.com/Chayanon-Ninyawee/KMIDS-GFM-Future-Engineer-2025/commit/85d791cdff591413cbcea0868593d4c8bff49ce2))
* List motor driver specs ([2c01a60](https://github.com/Chayanon-Ninyawee/KMIDS-GFM-Future-Engineer-2025/commit/2c01a6067dbaeaf319dcd8a7db4ddc2290dffa5f))
* Make expandable buttons bigger ([f7bfa6b](https://github.com/Chayanon-Ninyawee/KMIDS-GFM-Future-Engineer-2025/commit/f7bfa6b1f6524e986e5454d903809090477ee418))
* Move chassis design to mobility management ([4204fe4](https://github.com/Chayanon-Ninyawee/KMIDS-GFM-Future-Engineer-2025/commit/4204fe4ab57e0ca613bb830f41ed3af460f1cdd8))
* Move robot pictures to section 1 ([00a8cd6](https://github.com/Chayanon-Ninyawee/KMIDS-GFM-Future-Engineer-2025/commit/00a8cd67c2828f2c4f869c0b11a4b702a7ac2fac))
* Move shop link to bill of materials ([4c3d603](https://github.com/Chayanon-Ninyawee/KMIDS-GFM-Future-Engineer-2025/commit/4c3d603715a35961e2e2d8b90497e9bc876958c5))
* Move transistor and motor driver to power section ([3fbc61c](https://github.com/Chayanon-Ninyawee/KMIDS-GFM-Future-Engineer-2025/commit/3fbc61c125a3a6f685bdf8d70c3d7d813805b9e3))
* Move video to section 1 ([7f7bce7](https://github.com/Chayanon-Ninyawee/KMIDS-GFM-Future-Engineer-2025/commit/7f7bce793345c478f2aed16eff83ffce75bf8f30))
* Reformat building instruction pictures ([bc69ffb](https://github.com/Chayanon-Ninyawee/KMIDS-GFM-Future-Engineer-2025/commit/bc69ffb76591f80559d4ac9b9a4551323f55ca86))
* Remove lines ([8b62132](https://github.com/Chayanon-Ninyawee/KMIDS-GFM-Future-Engineer-2025/commit/8b6213213ebd993ee3f5919665772d8b47e73d12))

## [0.1.5](https://github.com/Chayanon-Ninyawee/KMIDS-GFM-Future-Engineer-2025/compare/v0.1.4...v0.1.5) (2025-10-08)

### Documentation

* Add detailed build settings for each part ([599b20d](https://github.com/Chayanon-Ninyawee/KMIDS-GFM-Future-Engineer-2025/commit/599b20d4a7740aa936c3569951161c15d32b13f4))
* Add pictures to build instructions 1 and 2 ([e590e7e](https://github.com/Chayanon-Ninyawee/KMIDS-GFM-Future-Engineer-2025/commit/e590e7ecd25fb36c9dfaec85c475b752ec59f770))
* Add step 1 building instruction pics ([7952c55](https://github.com/Chayanon-Ninyawee/KMIDS-GFM-Future-Engineer-2025/commit/7952c55b84d7470fdd5a4bac8349f7d009f7c4a5))
* Add step 2 building instruction pics ([261c6cd](https://github.com/Chayanon-Ninyawee/KMIDS-GFM-Future-Engineer-2025/commit/261c6cdfc5fa5743bc3ba7befe4e394326e637a7))
* Add table of parts in step 0 of building instructions ([839d939](https://github.com/Chayanon-Ninyawee/KMIDS-GFM-Future-Engineer-2025/commit/839d9392398777d01b835b6fef8596d37430fadb))
* Addjustification for jumper wires in 3.4 ([b5b08ef](https://github.com/Chayanon-Ninyawee/KMIDS-GFM-Future-Engineer-2025/commit/b5b08ef6e73aaa7c43a7016c7405c39e97cdd89d))
* Change the filename of wiring diagram ([58439b1](https://github.com/Chayanon-Ninyawee/KMIDS-GFM-Future-Engineer-2025/commit/58439b1e07b8f0ad7eaa64dcfb5516af9547daeb))
* Change wording to ensure consistent wording ([b917324](https://github.com/Chayanon-Ninyawee/KMIDS-GFM-Future-Engineer-2025/commit/b9173245313bc13a8a5007ee9ff1b6772ba1aeac))
* Format table of contents ([fcd5466](https://github.com/Chayanon-Ninyawee/KMIDS-GFM-Future-Engineer-2025/commit/fcd54661abd39eb1a1c79a33cf95ec935ebb3be0))
* Remove numbering for STL and Slicer files ([dd9b4ce](https://github.com/Chayanon-Ninyawee/KMIDS-GFM-Future-Engineer-2025/commit/dd9b4cecc3bd34d5f75783eb74916a2f06c3f8c0))
* Remove redundant table of content sections ([d262324](https://github.com/Chayanon-Ninyawee/KMIDS-GFM-Future-Engineer-2025/commit/d26232419e334353e47b3c6293f5753fc59b114b))
* Update wiring diagram picture ([af80edf](https://github.com/Chayanon-Ninyawee/KMIDS-GFM-Future-Engineer-2025/commit/af80edfd91f8ecf0d969b87f492c236a3e709adf))

## [0.1.4](https://github.com/Chayanon-Ninyawee/KMIDS-GFM-Future-Engineer-2025/compare/v0.1.3...v0.1.4) (2025-10-05)

### Documentation

* Add docker reference to 7.2 upload instructions ([57b3ee5](https://github.com/Chayanon-Ninyawee/KMIDS-GFM-Future-Engineer-2025/commit/57b3ee5c7915e74bac007470a825d82353379cf4))
* Add links to gcode in step 0 in build instructions ([eb67782](https://github.com/Chayanon-Ninyawee/KMIDS-GFM-Future-Engineer-2025/commit/eb677827036aec9cdfe113853c7ac18e85d82d91))
* Add more detailed instructions on mounting electronics. ([c64c20a](https://github.com/Chayanon-Ninyawee/KMIDS-GFM-Future-Engineer-2025/commit/c64c20a71c99d5bdd8fd51189494a97deeb27eee))
* Add rough building instructions ([a2df991](https://github.com/Chayanon-Ninyawee/KMIDS-GFM-Future-Engineer-2025/commit/a2df991b6f364adab4f91c61eda054e3dfc7a239))
* Add settings for step 0 of building instruction ([f12dc55](https://github.com/Chayanon-Ninyawee/KMIDS-GFM-Future-Engineer-2025/commit/f12dc55ec8e0a838fc21e67b4290b07742654c8e))
* Add slicer files to section 9 ([82b4cd2](https://github.com/Chayanon-Ninyawee/KMIDS-GFM-Future-Engineer-2025/commit/82b4cd2f8c99fe08654f15a04e1d5c7538108848))
* Add youtube thumbnail, revise step 0 in building instructions ([93344e8](https://github.com/Chayanon-Ninyawee/KMIDS-GFM-Future-Engineer-2025/commit/93344e87ae38808ff8154b777da821a253b11609))
* Clarify details in step 3 and 4 and add amount specifications to screws ([0d9b6bb](https://github.com/Chayanon-Ninyawee/KMIDS-GFM-Future-Engineer-2025/commit/0d9b6bb788ec16e06f6baeab1791e7a7567600a5))
* Clarify instructions and components used for step 1 ([0bf8c0f](https://github.com/Chayanon-Ninyawee/KMIDS-GFM-Future-Engineer-2025/commit/0bf8c0f9dc372334abd769c0dc24b9ef68b7311d))
* Clarify instructions and components used for step 2 ([9713236](https://github.com/Chayanon-Ninyawee/KMIDS-GFM-Future-Engineer-2025/commit/9713236e5ee11602b3c55054a4d9823093cb5b8f))
* Format documentation ([4c93272](https://github.com/Chayanon-Ninyawee/KMIDS-GFM-Future-Engineer-2025/commit/4c9327200f108f8f3dd8861bbfdbdc44ffce339e))
* Format section 9 points ([d463f2e](https://github.com/Chayanon-Ninyawee/KMIDS-GFM-Future-Engineer-2025/commit/d463f2efeac19e41bbc6483077a0cb600fb4b02f))
* Make headings in section 9 smaller ([000036b](https://github.com/Chayanon-Ninyawee/KMIDS-GFM-Future-Engineer-2025/commit/000036be7345818cc1135ae113e69698a026631b))
* Remove part 5 ([bd8a42c](https://github.com/Chayanon-Ninyawee/KMIDS-GFM-Future-Engineer-2025/commit/bd8a42ca6160a693866ba758f1b30297fd4481f0))
* Remove redundant page lines and add back to top ([2c58b3f](https://github.com/Chayanon-Ninyawee/KMIDS-GFM-Future-Engineer-2025/commit/2c58b3f67c8a28baf3618b977d6b919b9a518984))
* Remove step 4 and 5 from building instructions ([ebf4530](https://github.com/Chayanon-Ninyawee/KMIDS-GFM-Future-Engineer-2025/commit/ebf4530555f4672ec6d6e4cd039ddac2023610bb))
* Revise building instruction 10 Step 3 ([2d383c5](https://github.com/Chayanon-Ninyawee/KMIDS-GFM-Future-Engineer-2025/commit/2d383c50f395d0e84ce41b486eebb9bc3a44ec5c))
* Revise building instructions step 1 ([881aaaa](https://github.com/Chayanon-Ninyawee/KMIDS-GFM-Future-Engineer-2025/commit/881aaaa4667308d5a7e3340174082116c6951168))
* Revise step 4 of build instructions ([c98e1ac](https://github.com/Chayanon-Ninyawee/KMIDS-GFM-Future-Engineer-2025/commit/c98e1ac5de7580313c97c63cd48d7e18bc7efcca))
* Specify 9.2 on gcode and settings ([d4a1ae5](https://github.com/Chayanon-Ninyawee/KMIDS-GFM-Future-Engineer-2025/commit/d4a1ae53627eab244209a0736b67ad5bd9f4ec7a))

## [0.1.3](https://github.com/Chayanon-Ninyawee/KMIDS-GFM-Future-Engineer-2025/compare/v0.1.2...v0.1.3) (2025-10-05)

### CI/CD

* Fix Build cross-compile image do not cache when it should ([3f68c11](https://github.com/Chayanon-Ninyawee/KMIDS-GFM-Future-Engineer-2025/commit/3f68c11013e12e49cdb94c5bd05000874614d191))

## [0.1.2](https://github.com/Chayanon-Ninyawee/KMIDS-GFM-Future-Engineer-2025/compare/v0.1.1...v0.1.2) (2025-10-05)

### Bug Fixes

* Fix obstacle challenge ([6cd3a1e](https://github.com/Chayanon-Ninyawee/KMIDS-GFM-Future-Engineer-2025/commit/6cd3a1eddd2aa1fcef109c3c50347701d5c9c1c7))
* Make combineTraffixLightInfo more robust by using ray tracing algorithm ([84aa4b0](https://github.com/Chayanon-Ninyawee/KMIDS-GFM-Future-Engineer-2025/commit/84aa4b03220b330a2d8ca8bf174834a2eb74af3c))
* Make getTrafficLightPoints get the deltaPose to properly transpose the trafficLight points according the the data from the IMU ([57aebce](https://github.com/Chayanon-Ninyawee/KMIDS-GFM-Future-Engineer-2025/commit/57aebce9f154749343c2359b11b67e36225c9172))
* Obstacle challenge: make sure that there can't be outer traffic light in the starting section ([f5242a5](https://github.com/Chayanon-Ninyawee/KMIDS-GFM-Future-Engineer-2025/commit/f5242a5a48089b11e92739c514d174395cca1585))
* Remove robotDeltaPose from combineTrafficLightInfo so that the trafficLight point does not get transpose twice ([2284e31](https://github.com/Chayanon-Ninyawee/KMIDS-GFM-Future-Engineer-2025/commit/2284e31a812e0865ba4937bc75da7bd696f85abe))
* Set camera exposure time to be manual instead of auto ([aaeec12](https://github.com/Chayanon-Ninyawee/KMIDS-GFM-Future-Engineer-2025/commit/aaeec126056323174500699093fdaf2b48711646))

### Miscellaneous Tasks

* Change camera HSV color mask ([adaaf51](https://github.com/Chayanon-Ninyawee/KMIDS-GFM-Future-Engineer-2025/commit/adaaf517eecb2de688a8c1f458a08094a0e837ec))
* Change camera HSV color mask ([e4631d7](https://github.com/Chayanon-Ninyawee/KMIDS-GFM-Future-Engineer-2025/commit/e4631d7abc60d150468c65d48974d6024d88ac3a))
* Change lidar filter ([6862b26](https://github.com/Chayanon-Ninyawee/KMIDS-GFM-Future-Engineer-2025/commit/6862b2691ffeb8af4e35f84e03b4115b26cbf7dc))

### CI/CD

* Restore the correct cache key ([1db539f](https://github.com/Chayanon-Ninyawee/KMIDS-GFM-Future-Engineer-2025/commit/1db539f4f3351ac3896e31bbabdcd57d9fef8b79))
* Use Docker BuildKit’s built-in GitHub Actions cache ([c04cd26](https://github.com/Chayanon-Ninyawee/KMIDS-GFM-Future-Engineer-2025/commit/c04cd26f19d3944ed7b921046e18b6183fc745ff))

## [0.1.1](https://github.com/Chayanon-Ninyawee/KMIDS-GFM-Future-Engineer-2025/compare/v0.1.0...v0.1.1) (2025-10-01)

### CI/CD

* Make cache key base on run number instead of hash since same Dockerfile can have difference cache ([137cafb](https://github.com/Chayanon-Ninyawee/KMIDS-GFM-Future-Engineer-2025/commit/137cafbd318d167ce982e7589d4ed60951a38f6c))

## [0.1.0](https://github.com/Chayanon-Ninyawee/KMIDS-GFM-Future-Engineer-2025/compare/v0.0.2...v0.1.0) (2025-10-01)

### Features

* Add build-log_viewer-native.sh ([46b4f8d](https://github.com/Chayanon-Ninyawee/KMIDS-GFM-Future-Engineer-2025/commit/46b4f8db8afb447ea749bc71274858b2262cde8f))
* Make log_viewer use openChallenge.bin scanMap.bin or obstacleChallenge.bin to get the timestamp of the main loop ([838f1af](https://github.com/Chayanon-Ninyawee/KMIDS-GFM-Future-Engineer-2025/commit/838f1af3a89877ece414e329f4776f5a47dfcaab))

### Bug Fixes

* Delete the logger after the main loop end to prevent memory leak ([525a663](https://github.com/Chayanon-Ninyawee/KMIDS-GFM-Future-Engineer-2025/commit/525a663ebacddf0148812b84ca59aa037737956a))
* Faster log_viewer ([a841954](https://github.com/Chayanon-Ninyawee/KMIDS-GFM-Future-Engineer-2025/commit/a841954135d40a6fec8294d855c29df0418455b0))
* Fix build-log_viewer-native.sh so it remove the correct build_native/ not build/ when clean ([a564217](https://github.com/Chayanon-Ninyawee/KMIDS-GFM-Future-Engineer-2025/commit/a564217cd6a02b0c59134d7821d9cf34b436d04c))
* Flush file when logger is deconstructed ([13ec9c6](https://github.com/Chayanon-Ninyawee/KMIDS-GFM-Future-Engineer-2025/commit/13ec9c6e77aa946786750c625d8c289f405e3f9b))
* Make lidar_processor::getTrafficLightPoints work properly with the new RPLidar S2 ([97daacb](https://github.com/Chayanon-Ninyawee/KMIDS-GFM-Future-Engineer-2025/commit/97daacb6d2a7ba19c889be637c1c47c20212a4d0))
* Make the bin/ output to the correct directory instead of hardcoded value ([aadc8df](https://github.com/Chayanon-Ninyawee/KMIDS-GFM-Future-Engineer-2025/commit/aadc8df68b5e16c6ad4058e7040a01db2065dd4b))

### Miscellaneous Tasks

* Change camera color HSV mask ([5665760](https://github.com/Chayanon-Ninyawee/KMIDS-GFM-Future-Engineer-2025/commit/56657605286af5677d468daf21b5acffc08f3a15))

## [0.0.2](https://github.com/Chayanon-Ninyawee/KMIDS-GFM-Future-Engineer-2025/compare/v0.0.1...v0.0.2) (2025-09-29)

### Bug Fixes

* Change parking walls angle threshold to ignore shadow parking walls ([c587c09](https://github.com/Chayanon-Ninyawee/KMIDS-GFM-Future-Engineer-2025/commit/c587c095b9e35ca17550dd07082c737e9496604d))

## [0.0.1](https://github.com/Chayanon-Ninyawee/KMIDS-GFM-Future-Engineer-2025/compare/v0.0.0...v0.0.1) (2025-09-29)

### CI/CD

* Add github workflows to automate release ([7a904f9](https://github.com/Chayanon-Ninyawee/KMIDS-GFM-Future-Engineer-2025/commit/7a904f92845440cf548a05d511784d56ab686864))

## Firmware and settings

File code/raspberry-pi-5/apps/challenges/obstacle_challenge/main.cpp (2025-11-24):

#include "camera_module.h"
#include "camera_processor.h"
#include "combined_processor.h"
#include "direction.h"
#include "lidar_module.h"
#include "lidar_processor.h"
#include "pico2_module.h"
#include "pid_controller.h"
#include "robot_pose_struct.h"

#include <algorithm>
#include <atomic>
#include <chrono>
#include <csignal>
#include <filesystem>
#include <iostream>
#include <map>
#include <memory>
#include <optional>
#include <thread>
#include <wiringPi.h>

// --- Global Signal Handler ---
volatile std::sig_atomic_t stop_flag = 0;

void signalHandler(int signum) {
    std::cout << "\nInterrupt signal (" << signum << ") received.\n";
    stop_flag = 1;
}

// --- Constants ---
// Pins
const int BUTTON_PIN = 16;

// Camera
const uint32_t CAM_WIDTH = 1296;
const uint32_t CAM_HEIGHT = 972;
const float CAM_HFOV = 98.0f;

const auto cameraOptionCallback = [](lccv::PiCamera &cam) {
    libcamera::ControlList &camControls = cam.getControlList();

    cam.options->video_width = CAM_WIDTH;
    cam.options->video_height = CAM_HEIGHT;
    cam.options->framerate = 30.0f;

    camControls.set(controls::AnalogueGainMode, controls::AnalogueGainModeEnum::AnalogueGainModeManual);
    camControls.set(controls::ExposureTimeMode, controls::ExposureTimeModeEnum::ExposureTimeModeManual);
    camControls.set(controls::AwbEnable, false);

    cam.options->awb_gain_r = 0.90;
    cam.options->awb_gain_b = 1.5;

    cam.options->brightness = 0.1;
    cam.options->sharpness = 1;
    cam.options->saturation = 1.5;
    cam.options->contrast = 1;
    cam.options->gain = 5;
    cam.options->shutter = 30000;
};

// Robot Control Parameters

const float TARGET_OUTER_WALL_DISTANCE = 0.50;
const float TARGET_OUTER_WALL_OUTER1_DISTANCE = 0.43;
const float TARGET_OUTER_WALL_OUTER2_DISTANCE = 0.25;
const float TARGET_OUTER_WALL_INNER1_DISTANCE = 0.62;
const float TARGET_OUTER_WALL_INNER2_DISTANCE = 0.76;
const float TARGET_OUTER_WALL_DISTANCE_PARKING_CCW = 0.29f;
const float TARGET_OUTER_WALL_DISTANCE_PARKING_CW = 0.31f;
const float TARGET_OUTER_WALL_UTURN_PARKING_DISTANCE_CCW = 0.75f;
const float TARGET_OUTER_WALL_UTURN_PARKING_DISTANCE_CW = 0.75f;

const float PRE_TURN_FRONT_WALL_DISTANCE = 1.20f;
const auto PRE_TURN_COOLDOWN = std::chrono::milliseconds(4000);

const float TURNING_FRONT_WALL_DISTANCE = 0.78f;
const float TURNING_FRONT_WALL_OUTER1_DISTANCE = 0.67f;
const float TURNING_FRONT_WALL_OUTER2_DISTANCE = 0.50f;
const float TURNING_FRONT_WALL_INNER1_DISTANCE = 0.97f;
const float TURNING_FRONT_WALL_INNER2_DISTANCE = 1.07f;
const float TURNING_FRONT_WALL_CCW_PARKING_DISTANCE = 0.59f;
const float TURNING_FRONT_WALL_CW_PARKING_DISTANCE = 0.59f;

const auto PRE_TURN_COOLDOWN_PUSH = std::chrono::milliseconds(2000);

const float TURNING_FRONT_WALL_DISTANCE_PUSH = 0.89f;
const float TURNING_FRONT_WALL_OUTER1_DISTANCE_PUSH = 0.76f;
const float TURNING_FRONT_WALL_OUTER2_DISTANCE_PUSH = 0.59f;
const float TURNING_FRONT_WALL_INNER1_DISTANCE_PUSH = 1.06f;
const float TURNING_FRONT_WALL_INNER2_DISTANCE_PUSH = 1.16f;

// Will just go and park EZ
const float CCW_PRE_PARKING_FRONT_WALL_DISTANCE = 1.20f;
const auto CCW_PRE_FIND_PARKING_DELAY = std::chrono::milliseconds(500);
// Will just go to uturn then go and use CW_PRE_PARKING
const float CCW_UTURN_PRE_PARKING_FRONT_WALL_DISTANCE = 0.80f;
const auto CCW_UTURN_PRE_FIND_PARKING_DELAY = std::chrono::milliseconds(1000);
// Will go over then reverse the go over again to make sure that the car aligned
const float CW_PRE_PARKING_FRONT_WALL_DISTANCE = 1.80f;
const auto CW_PRE_FIND_PARKING_DELAY_1 = std::chrono::milliseconds(1000);
const auto CW_PRE_FIND_PARKING_DELAY_2 = std::chrono::milliseconds(3000);
// Will just go to uturn then go and use CCW_PRE_PARKING
const float CW_UTURN_PRE_PARKING_FRONT_WALL_DISTANCE = 1.00f;
const auto CW_UTURN_PRE_FIND_PARKING_DELAY = std::chrono::milliseconds(1000);

const float FORWARD_MOTOR_SPEED = 3.0f;
const float FORWARD_MOTOR_SPEED_PUSH = 4.5f;
const float HEADING_TOLERANCE_DEGREES_TURN = 30.0f;
const float HEADING_TOLERANCE_DEGREES_UTURN = 40.0f;

// PID Gains
const double HEADING_PID_P = 3.0;
const double HEADING_PID_I = 0.0;
const double HEADING_PID_D = 0.0;
const double WALL_PID_P = 180.0;
const double WALL_PID_I = 0.0;
const double WALL_PID_D = 0.0;

// --- Helper Functions ---
float normalizeAngle(float angle) {
    angle = std::fmod(angle + 180.0f, 360.0f);
    if (angle < 0) angle += 360.0f;
    return angle - 180.0f;
}

// --- Main Robot Class ---

class Robot
{
public:
    enum class Mode
    {
        UNKNOWN,
        CCW_UNPARK_1,
        CCW_UNPARK_2,
        CCW_UNPARK_3,
        CCW_UNPARK_4,
        CW_UNPARK_1,
        CW_UNPARK_2,
        NORMAL,
        PRE_TURN,
        TURNING,
        CW_PRE_FIND_PARKING_1,
        CW_PRE_FIND_PARKING_2,
        CW_UTURN_PRE_FIND_PARKING_1,
        CW_UTURN_PRE_FIND_PARKING_2,
        CW_UTURN_PRE_FIND_PARKING_3,
        CCW_PRE_FIND_PARKING,
        CCW_UTURN_PRE_FIND_PARKING_1,
        CCW_UTURN_PRE_FIND_PARKING_2,
        CCW_UTURN_PRE_FIND_PARKING_3,
        CCW_FIND_PARKING,
        CW_FIND_PARKING,
        PARKING_1,
        PARKING_2,
        PARKING_3,
        STOP
    };

    Robot(LidarModule &lidar, Pico2Module &pico2, CameraModule &camera, Logger &obstacleChallengeLogger)
        : lidar_(lidar)
        , pico2_(pico2)
        , camera_(camera)
        , obstacleChallengeLogger_(obstacleChallengeLogger)
        , headingPid_(HEADING_PID_P, HEADING_PID_I, HEADING_PID_D, -100.0, 100.0)
        , wallPid_(WALL_PID_P, WALL_PID_I, WALL_PID_D, -90.0, 90.0) {
        headingPid_.setActive(true);
        wallPid_.setActive(true);
    }

    /**
     * @brief The main update loop for the robot's logic.
     * @param dt The time delta since the last update in seconds.
     */
    void update(float dt) {
        auto robotDataOpt = updateRobotData(dt);
        if (!robotDataOpt) {
            // Not enough data yet, do nothing.
            pico2_.setMovementInfo(0.0f, 0.0f);
            return;
        }

        RobotData robotData = *robotDataOpt;

        bool instantUpdate;
        do {
            instantUpdate = false;
            switch (mode_) {
            case Mode::UNKNOWN:
                std::cout << "[Mode::UNKNOWN]\n";
                instantUpdate = false;
                pico2_.setMovementInfo(0.0f, 0.0f);
                return;
            case Mode::CCW_UNPARK_1:
                std::cout << "[Mode::CCW_UNPARK_1]\n";
                instantUpdate = updateCcwUnpark1State(robotData);
                break;
            case Mode::CCW_UNPARK_2:
                std::cout << "[Mode::CCW_UNPARK_2]\n";
                instantUpdate = updateCcwUnpark2State(robotData);
                break;
            case Mode::CCW_UNPARK_3:
                std::cout << "[Mode::CCW_UNPARK_3]\n";
                instantUpdate = updateCcwUnpark3State(robotData);
                break;
            case Mode::CCW_UNPARK_4:
                std::cout << "[Mode::CCW_UNPARK_4]\n";
                instantUpdate = updateCcwUnpark4State(robotData);
                break;
            case Mode::CW_UNPARK_1:
                std::cout << "[Mode::CW_UNPARK_1]\n";
                instantUpdate = updateCwUnpark1State(robotData);
                break;
            case Mode::CW_UNPARK_2:
                std::cout << "[Mode::CW_UNPARK_2]\n";
                instantUpdate = updateCwUnpark2State(robotData);
                break;
            case Mode::NORMAL:
                std::cout << "[Mode::NORMAL]\n";
                instantUpdate = updateNormalState(robotData);
                break;
            case Mode::PRE_TURN:
                std::cout << "[Mode::PRE_TURN]\n";
                instantUpdate = updatePreTurnState(robotData);
                break;
            case Mode::TURNING:
                std::cout << "[Mode::TURNING]\n";
                instantUpdate = updateTurningState(robotData);
                break;
            case Mode::CW_PRE_FIND_PARKING_1:
                std::cout << "[Mode::CW_PRE_FIND_PARKING_1]\n";
                instantUpdate = updateCwPreFindParking1State(robotData);
                break;
            case Mode::CW_PRE_FIND_PARKING_2:
                std::cout << "[Mode::CW_PRE_FIND_PARKING_2]\n";
                instantUpdate = updateCwPreFindParking2State(robotData);
                break;
            case Mode::CW_UTURN_PRE_FIND_PARKING_1:
                std::cout << "[Mode::CW_UTURN_PRE_FIND_PARKING_1]\n";
                instantUpdate = updateCwUturnPreFindParking1State(robotData);
                break;
            case Mode::CW_UTURN_PRE_FIND_PARKING_2:
                std::cout << "[Mode::CW_UTURN_PRE_FIND_PARKING_2]\n";
                instantUpdate = updateCwUturnPreFindParking2State(robotData);
                break;
            case Mode::CW_UTURN_PRE_FIND_PARKING_3:
                std::cout << "[Mode::CW_UTURN_PRE_FIND_PARKING_3]\n";
                instantUpdate = updateCwUturnPreFindParking3State(robotData);
                break;
            case Mode::CCW_PRE_FIND_PARKING:
                std::cout << "[Mode::CCW_PRE_FIND_PARKING]\n";
                instantUpdate = updateCcwPreFindParkingState(robotData);
                break;
            case Mode::CCW_UTURN_PRE_FIND_PARKING_1:
                std::cout << "[Mode::CCW_UTURN_PRE_FIND_PARKING_1]\n";
                instantUpdate = updateCcwUturnPreFindParking1State(robotData);
                break;
            case Mode::CCW_UTURN_PRE_FIND_PARKING_2:
                std::cout << "[Mode::CCW_UTURN_PRE_FIND_PARKING_2]\n";
                instantUpdate = updateCcwUturnPreFindParking2State(robotData);
                break;
            case Mode::CCW_UTURN_PRE_FIND_PARKING_3:
                std::cout << "[Mode::CCW_UTURN_PRE_FIND_PARKING_3]\n";
                instantUpdate = updateCcwUturnPreFindParking3State(robotData);
                break;
            case Mode::CCW_FIND_PARKING:
                std::cout << "[Mode::CCW_FIND_PARKING]\n";
                instantUpdate = updateCcwFindParkingState(robotData);
                break;
            case Mode::CW_FIND_PARKING:
                std::cout << "[Mode::CW_FIND_PARKING]\n";
                instantUpdate = updateCwFindParkingState(robotData);
                break;
            case Mode::PARKING_1:
                std::cout << "[Mode::PARKING_1]\n";
                instantUpdate = updateParking1State(robotData);
                break;
            case Mode::PARKING_2:
                std::cout << "[Mode::PARKING_2]\n";
                instantUpdate = updateParking2State(robotData);
                break;
            case Mode::PARKING_3:
                std::cout << "[Mode::PARKING_3]\n";
                instantUpdate = updateParking3State(robotData);
                break;
            case Mode::STOP:
                motorSpeed_ = 0.0f;
                steeringPercent_ = 0.0f;
                stop_flag = 1;
                break;
            }
        } while (instantUpdate && !stop_flag);

        bool isUnparking =
            (mode_ == Mode::CCW_UNPARK_1 || mode_ == Mode::CCW_UNPARK_2 || mode_ == Mode::CCW_UNPARK_3 || mode_ == Mode::CCW_UNPARK_4 ||
             mode_ == Mode::CW_UNPARK_1 || mode_ == Mode::CW_UNPARK_2);
        bool isParking = (mode_ == Mode::PARKING_1 || mode_ == Mode::PARKING_2 || mode_ == Mode::PARKING_3);
        if (mode_ != Mode::STOP && !isParking && !isUnparking) {
            calculateSteering(dt, robotData);
        }

        pico2_.setMovementInfo(motorSpeed_, steeringPercent_);
    }

private:
    LidarModule &lidar_;
    Pico2Module &pico2_;
    CameraModule &camera_;
    Logger &obstacleChallengeLogger_;
    PIDController headingPid_;
    PIDController wallPid_;

    // --- State Variables ---
    Mode mode_ = Mode::UNKNOWN;
    Direction headingDirection_ = Direction::NORTH;
    std::optional<float> initialHeading_;
    std::optional<RotationDirection> turnDirection_;
    int turnCount_ = 0;

    // Mode mode_ = Mode::NORMAL;
    // Direction headingDirection_ = Direction::NORTH;
    // std::optional<float> initialHeading_;
    // std::optional<RotationDirection> turnDirection_ = RotationDirection::CLOCKWISE;
    // int turnCount_ = 12;

    // Mode mode_ = Mode::NORMAL;
    // Direction headingDirection_ = Direction::NORTH;
    // std::optional<float> initialHeading_;
    // std::optional<RotationDirection> turnDirection_ = RotationDirection::COUNTER_CLOCKWISE;
    // int turnCount_ = 12;

    // Mode mode_ = Mode::CCW_UNPARK_1;
    // Direction headingDirection_ = Direction::NORTH;
    // std::optional<float> initialHeading_;
    // std::optional<RotationDirection> turnDirection_ = RotationDirection::COUNTER_CLOCKWISE;
    // int turnCount_ = 0;

    // Mode mode_ = Mode::CW_UNPARK_1;
    // Direction headingDirection_ = Direction::NORTH;
    // std::optional<float> initialHeading_;
    // std::optional<RotationDirection> turnDirection_ = RotationDirection::CLOCKWISE;
    // int turnCount_ = 0;

    float targetOuterWallDistance_ = TARGET_OUTER_WALL_DISTANCE;
    float turningFrontWallDistance_ = TURNING_FRONT_WALL_DISTANCE;
    double startEncoderAngle_ = 0.0;

    std::map<std::pair<Segment, SegmentLocation>, std::vector<combined_processor::ClassifiedTrafficLight>> detectionHistory_;
    std::map<std::pair<Segment, SegmentLocation>, combined_processor::ClassifiedTrafficLight> trafficLightMap_;

    bool isNormalNoBlockWhenEnter = false;

    // Timers
    std::optional<std::chrono::steady_clock::time_point> lastPreTurnTimestamp_;
    std::optional<std::chrono::steady_clock::time_point> timer_;

    // Outputs
    float motorSpeed_ = 0.0f;
    float steeringPercent_ = 0.0f;

    struct RobotData {
        float heading;
        double encoderAngle;
        std::optional<lidar_processor::LineSegment> frontWall, backWall, outerWall, innerWall;
        std::vector<lidar_processor::LineSegment> parkingWalls;
    };

    // --- Method Implementations ---

    /**
     * @brief Calculates the recent rate of heading change in degrees per second.
     *
     * It compares the latest heading measurement with one from a fixed number of samples
     * in the past to determine the angular velocity.
     *
     * @param picoHistory The vector of recent pico2 data points.
     * @return The angular velocity in degrees per second.
     */
    float calculateRecentHeadingRate(const std::vector<TimedPico2Data> &picoHistory) {
        // The number of samples to look back for the calculation.
        // (size - 1) vs (size - 13) is a 12-sample difference.
        const size_t HEADING_RATE_LOOKBACK = 12;

        if (picoHistory.size() < HEADING_RATE_LOOKBACK + 1) {
            return 0.0f;  // Not enough data to compute
        }

        const auto &latestData = picoHistory.back();
        const auto &olderData = picoHistory[picoHistory.size() - 1 - HEADING_RATE_LOOKBACK];

        // Calculate the shortest angle difference (handles 360->0 wrap-around)
        float diff_deg = latestData.euler.h - olderData.euler.h;
        diff_deg = std::fmod(diff_deg + 180.0f, 360.0f) - 180.0f;

        // Use std::chrono for a type-safe and readable time difference calculation
        std::chrono::duration<float> timeElapsed = latestData.timestamp - olderData.timestamp;
        float timeElapsed_s = timeElapsed.count();

        // Avoid division by zero
        if (timeElapsed_s <= 0.0f) {
            return 0.0f;
        }

        return diff_deg / timeElapsed_s;
    }

    std::optional<RobotData> updateRobotData(float dt) {
        std::vector<TimedLidarData> timedLidarDatas;
        lidar_.getAllTimedLidarData(timedLidarDatas);
        if (timedLidarDatas.size() < lidar_.bufferSize()) return std::nullopt;

        std::vector<TimedPico2Data> timedPico2Datas;
        pico2_.getAllTimedData(timedPico2Datas);
        if (timedPico2Datas.size() < pico2_.bufferSize()) return std::nullopt;

        std::vector<TimedFrame> timedFrames;
        camera_.getAllTimedFrame(timedFrames);
        if (timedFrames.size() < camera_.bufferSize()) return std::nullopt;

        auto &timedLidarData = timedLidarDatas.back();
        auto &timedPico2Data = timedPico2Datas.back();
        auto &timedFrame = timedFrames.back();

        // Log main loop timestamp
        auto now = std::chrono::steady_clock::now();
        uint64_t timestamp_ns = std::chrono::duration_cast<std::chrono::nanoseconds>(now.time_since_epoch()).count();
        struct {
            uint64_t lidarTimestamp_ns;
            uint64_t pico2Timestamp_ns;
            uint64_t cameraTimestamp_ns;
        } obstacleChallengeData{
            static_cast<uint64_t>(
                std::chrono::duration_cast<std::chrono::nanoseconds>(timedLidarData.timestamp.time_since_epoch()).count()
            ),
            static_cast<uint64_t>(
                std::chrono::duration_cast<std::chrono::nanoseconds>(timedPico2Data.timestamp.time_since_epoch()).count()
            ),
            static_cast<uint64_t>(std::chrono::duration_cast<std::chrono::nanoseconds>(timedFrame.timestamp.time_since_epoch()).count())
        };
        obstacleChallengeLogger_.writeData(timestamp_ns, &obstacleChallengeData, sizeof(obstacleChallengeData));

        if (!initialHeading_) {
            initialHeading_ = timedPico2Data.euler.h;
            return std::nullopt;
        }

        RobotData data;
        data.heading = timedPico2Data.euler.h - initialHeading_.value_or(0.0f);
        data.heading = std::fmod(data.heading, 360.0f);
        if (data.heading < 0.0f) data.heading += 360.0f;
        data.encoderAngle = timedPico2Data.encoderAngle;

        auto filteredLidarData = lidar_processor::filterLidarData(timedLidarData);
        auto deltaPose = combined_processor::aproximateRobotPose(filteredLidarData, timedPico2Datas);
        auto lineSegments = lidar_processor::getLines(filteredLidarData, deltaPose, 0.05f, 10, 0.10f, 0.10f, 18.0f, 0.20f);
        auto relativeWalls = lidar_processor::getRelativeWalls(lineSegments, headingDirection_, data.heading, 0.30f, 25.0f, 0.22f);
        auto resolvedWalls = lidar_processor::resolveWalls(relativeWalls);

        // TODO: Test this more extensively
        if (!turnDirection_) {
            auto unfilteredLineSegments = lidar_processor::getLines(timedLidarData, deltaPose, 0.05f, 10, 0.10f, 0.10f, 18.0f, 0.20f);
            auto unfilteredRelativeWalls =
                lidar_processor::getRelativeWalls(unfilteredLineSegments, headingDirection_, data.heading, 0.30f, 25.0f, 0.22f);
            turnDirection_ = lidar_processor::getTurnDirection(unfilteredRelativeWalls);
        }
        if (!turnDirection_) return std::nullopt;

        if (mode_ == Mode::UNKNOWN) {
            if (*turnDirection_ == RotationDirection::CLOCKWISE) {
                mode_ = Mode::CW_UNPARK_1;
            } else {
                mode_ = Mode::CCW_UNPARK_1;
            }
        }
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
int main() {
    std::signal(SIGINT, signalHandler);

    const char *home = std::getenv("HOME");
    if (!home) {
        std::cerr << "HOME environment variable not set" << std::endl;
        return -1;
    }
    std::string logFolder = std::string(home) + "/gfm_logs/obstacle_challenge";
    std::string timedstampedLogFolder = Logger::generateTimestampedFolder(logFolder);

    Logger lidarLogger(timedstampedLogFolder + "/lidar.bin");
    Logger pico2Logger(timedstampedLogFolder + "/pico2.bin");
    Logger cameraLogger(timedstampedLogFolder + "/camera.bin");
    Logger obstacleChallengeLogger(timedstampedLogFolder + "/obstacleChallenge.bin");

    LidarModule lidar(&lidarLogger);
    Pico2Module pico2(&pico2Logger);
    CameraModule camera(&cameraLogger, cameraOptionCallback);

    if (!lidar.initialize() || !lidar.start()) {
        std::cerr << "LidarModule initialization failed." << std::endl;
        return -1;
    }
    if (!pico2.initialize()) {
        std::cerr << "Pico2Module initialization failed." << std::endl;
        return -1;
    }
    if (!camera.start()) {
        std::cerr << "CameraModule failed to start." << std::endl;
        return -1;
    }

    Robot robot(lidar, pico2, camera, obstacleChallengeLogger);

    if (wiringPiSetupGpio() == -1) {
        std::cerr << "WiringPi setup failed." << std::endl;
        return -1;
    }
    pinMode(BUTTON_PIN, INPUT);
    pullUpDnControl(BUTTON_PIN, PUD_UP);

    std::cout << "Press the button to start..." << std::endl;
    while (digitalRead(BUTTON_PIN) == HIGH && !stop_flag) {
        std::this_thread::sleep_for(std::chrono::milliseconds(10));
    }

    if (!stop_flag) {
        std::cout << "Starting in 1.0 seconds..." << std::endl;
        std::this_thread::sleep_for(std::chrono::milliseconds(1000));

        lidar.startLogging();
        pico2.startLogging();
        camera.startLogging();

        const auto loopDuration = std::chrono::milliseconds(33);  // ~30 Hz
        auto lastTime = std::chrono::steady_clock::now();
        std::cout << "Robot running." << std::endl;
        while (!stop_flag) {
            auto loopStart = std::chrono::steady_clock::now();
            float dt = std::chrono::duration<float>(loopStart - lastTime).count();
            lastTime = loopStart;

            robot.update(dt);

            auto elapsed = std::chrono::steady_clock::now() - loopStart;
            if (elapsed < loopDuration) {
                std::this_thread::sleep_for(loopDuration - elapsed);
            }
        }
    } else {
        std::filesystem::remove_all(timedstampedLogFolder);
        std::cout << "Start aborted. Log folder removed." << std::endl;
    }

    std::cout << "Shutting down..." << std::endl;
    pico2.setMovementInfo(0.0f, 0.0f);
    lidar.stop();
    lidar.shutdown();
    pico2.shutdown();
    camera.stop();
    std::cout << "Shutdown complete." << std::endl;

    return 0;
}

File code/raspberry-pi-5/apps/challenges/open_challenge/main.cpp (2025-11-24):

#include "combined_processor.h"
#include "lidar_module.h"
#include "lidar_processor.h"
#include "lidar_struct.h"
#include "pico2_module.h"
#include "pico2_struct.h"
#include "pid_controller.h"

#include <atomic>
#include <chrono>
#include <csignal>
#include <filesystem>
#include <iostream>
#include <memory>
#include <optional>
#include <thread>
#include <wiringPi.h>

// --- Global Signal Handler ---
volatile std::sig_atomic_t stop_flag = 0;

void signalHandler(int signum) {
    std::cout << "\nInterrupt signal (" << signum << ") received.\n";
    stop_flag = 1;
}

// --- Constants ---
// Pins
const int BUTTON_PIN = 16;

// Robot Control Parameters

const float TARGET_OUTER_WALL_DISTANCE = 0.30f;

const float PRE_TURN_FRONT_WALL_DISTANCE = 1.20f;
const auto PRE_TURN_COOLDOWN = std::chrono::milliseconds(1500);

const float TURNING_FRONT_WALL_DISTANCE = 0.65f;

const float STOP_FRONT_WALL_DISTANCE = 1.80f;
const auto STOP_DELAY = std::chrono::milliseconds(100);

const float HEADING_TOLERANCE_DEGREES = 20.0f;
const float FORWARD_MOTOR_SPEED = 4.5f;
const int TOTAL_TURNS_TO_FINISH = 12;

// PID Gains
const double HEADING_PID_P = 3.0;
const double HEADING_PID_I = 0.0;
const double HEADING_PID_D = 0.0;
const double WALL_PID_P = 180.0;
const double WALL_PID_I = 0.0;
const double WALL_PID_D = 0.0;

// --- Helper Functions ---
/**
 * @brief Normalizes an angle to the range [-180, 180] degrees.
 * @param angle The angle in degrees.
 * @return The normalized angle.
 */
float normalizeAngle(float angle) {
    angle = std::fmod(angle + 180.0f, 360.0f);
    if (angle < 0) {
        angle += 360.0f;
    }
    return angle - 180.0f;
}

// --- Main Robot Class ---

class Robot
{
public:
    enum class Mode
    {
        NORMAL,
        PRE_TURN,
        TURNING,
        PRE_STOP,
        STOP
    };

    Robot(LidarModule &lidar, Pico2Module &pico2, Logger &openChallengeLogger)
        : lidar_(lidar)
        , pico2_(pico2)
        , openChallengeLogger_(openChallengeLogger)
        , headingPid_(HEADING_PID_P, HEADING_PID_I, HEADING_PID_D, -100.0, 100.0)
        , wallPid_(WALL_PID_P, WALL_PID_I, WALL_PID_D, -90.0, 90.0) {
        // Activate PIDs. The wall PID will be toggled by the state machine.
        headingPid_.setActive(true);
        wallPid_.setActive(true);
    }

    /**
     * @brief The main update loop for the robot's logic.
     * @param dt The time delta since the last update in seconds.
     */
    void update(float dt) {
        auto robotDataOpt = updateRobotData(dt);
        if (!robotDataOpt) {
            // Not enough data yet, do nothing.
            pico2_.setMovementInfo(0.0f, 0.0f);
            return;
        }

        RobotData robotData = *robotDataOpt;

        bool instantUpdate;
        do {
            instantUpdate = false;
            switch (mode_) {
            case Mode::NORMAL:
                std::cout << "[Mode::NORMAL]\n";
                instantUpdate = updateNormalState(robotData);
                break;
            case Mode::PRE_TURN:
                std::cout << "[Mode::PRE_TURN]\n";
                instantUpdate = updatePreTurnState(robotData);
                break;
            case Mode::TURNING:
                std::cout << "[Mode::TURNING]\n";
                instantUpdate = updateTurningState(robotData);
                break;
            case Mode::PRE_STOP:
                std::cout << "[Mode::PRE_STOP]\n";
                instantUpdate = updatePreStopState(robotData);
                break;
            case Mode::STOP:
                std::cout << "[Mode::STOP]\n";
                motorSpeed_ = 0.0f;
                steeringPercent_ = 0.0f;
                stop_flag = 1;
                break;
            }
        } while (instantUpdate && !stop_flag);

        if (mode_ != Mode::STOP) {
            calculateSteering(dt, robotData);
        }

        pico2_.setMovementInfo(motorSpeed_, steeringPercent_);
    }

private:
    // Store references to the hardware modules
    LidarModule &lidar_;
    Pico2Module &pico2_;
    Logger &openChallengeLogger_;

    // PID controllers
    PIDController headingPid_;
    PIDController wallPid_;

    // Robot state
    Mode mode_ = Mode::NORMAL;
    int turnCount_ = 0;
    Direction headingDirection_ = Direction::NORTH;
    std::optional<float> initialHeading_;
    std::optional<RotationDirection> turnDirection_;

    // State-specific timing
    std::optional<std::chrono::steady_clock::time_point> lastPreTurnTimestamp_;
    std::optional<std::chrono::steady_clock::time_point> preStopTimestamp_;

    // Outputs
    float motorSpeed_ = 0.0f;
    float steeringPercent_ = 0.0f;

    struct RobotData {
        float heading;

        std::optional<lidar_processor::LineSegment> frontWall;
        std::optional<lidar_processor::LineSegment> backWall;
        std::optional<lidar_processor::LineSegment> outerWall;
        std::optional<lidar_processor::LineSegment> innerWall;
    };

    /**
     * @brief Gathers sensor data, processes it, and updates internal RobotData.
     * @param dt Delta time.
     * @return An optional RobotData struct. Returns nullopt if data is incomplete.
     */
    std::optional<RobotData> updateRobotData(float dt) {
        std::vector<TimedLidarData> lidarDatas;
        lidar_.getAllTimedLidarData(lidarDatas);
        if (lidarDatas.size() < lidar_.bufferSize()) return std::nullopt;

        std::vector<TimedPico2Data> pico2Datas;
        pico2_.getAllTimedData(pico2Datas);
        if (pico2Datas.size() < pico2_.bufferSize()) return std::nullopt;

        if (!initialHeading_) {
            initialHeading_ = pico2Datas.back().euler.h;
            return std::nullopt;  // Wait for the next cycle to have a valid heading
        }

        // Log main loop timestamp
        auto now = std::chrono::steady_clock::now();
        uint64_t timestamp_ns = std::chrono::duration_cast<std::chrono::nanoseconds>(now.time_since_epoch()).count();
        struct {
            uint64_t lidarTimestamp_ns;
            uint64_t pico2Timestamp_ns;
        } openChallengeData{
            static_cast<uint64_t>(
                std::chrono::duration_cast<std::chrono::nanoseconds>(lidarDatas.back().timestamp.time_since_epoch()).count()
            ),
            static_cast<uint64_t>(
                std::chrono::duration_cast<std::chrono::nanoseconds>(pico2Datas.back().timestamp.time_since_epoch()).count()
            )
        };
        openChallengeLogger_.writeData(timestamp_ns, &openChallengeData, sizeof(openChallengeData));

        RobotData data;
        data.heading = pico2Datas.back().euler.h - *initialHeading_;
        data.heading = std::fmod(data.heading, 360.0f);
        if (data.heading < 0.0f) data.heading += 360.0f;
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

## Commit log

2025-03-28 Add SteeringAckermannModel
2025-09-01 Make the Pico2Module check for invalid EncoderAngle
2025-09-01 Make sure that encoderAngle never return 0 to ensure that thbe i2c is send properly
2025-09-01 Remove the encoderAngle == 0 check in the obstacle challenge and tune the parking
2025-09-01 Test and fix scan_map inner and outer
    [main.cpp]
2025-09-02 Fix the pico2_module logging
    [main.cpp, pico2_module.cpp]
2025-09-02 Fix i2c comm error
    [main.cpp]
2025-09-02 Fix i2c comm error (pi5 side)
    [pico2_module.cpp]
2025-09-02 Change camera mask setting
2025-09-02 Add pragma once to lidar_processor
2025-09-02 Fix obstable_challenge and test_lidar_cam
    [main.cpp]
2025-09-02 Print classifiedTrafficLight in log_viewer
2025-09-03 Add traffic light avoidance
    [main.cpp]
2025-09-03 Add better traffic light avoidance
    [main.cpp]
2025-09-03 Fix some obstacle_challenge syntax error
    [main.cpp]
2025-09-03 Fix bugs in obstacle_challenge
    [main.cpp]
2025-09-03 Add button to obstacle_challenge
2025-09-03 Make the button while loop respect interupt request
2025-09-03 Add button to open_challenge
2025-09-03 Add button to scan_map
2025-09-03 Attemp to fix left parking
    [main.cpp]
2025-09-03 Make CW_PRE_FIND_PARKING speed faster and make CW_FIND_PARKING not go to reverse immedietely
    [main.cpp]
2025-09-04 Attemp to fix the uturn before parking
    [main.cpp]
2025-09-21 Change lidar_module default baudrate for rplidar s2
2025-09-21 Change chassis and lidar_holder to fit rplidar s2
    [Chassis.FCStd, Chassis_1x.stl, FrontAssembly.FCStd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]
2025-09-21 Make Chassis back wheel holder screw mount tighter
    [Chassis.FCStd, Chassis_1x.stl, FrontAssembly.FCStd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]
2025-09-21 Slice LidarPlate
    [CE3V3KE_LidarPlate_1x.3mf]
2025-09-21 Slice Chassis
    [Chassis_1x.3mf]
2025-09-23 Fix i2c_master corrupted read data issue
    [i2c_master.cpp]
2025-09-25 Make logger start logging only when the button is pressed
2025-09-25 Change camera red gain
2025-09-29 fix: Add minClusterSize to lidar_processor::getTrafficLightPoints to remove the shadow traffc lights
    [lidar_processor.h]
2025-10-01 fix: Make lidar_processor::getTrafficLightPoints work properly with the new RPLidar S2
2025-10-01 fix: Delete the logger after the main loop end to prevent memory leak
    [main.cpp]
2025-10-01 chore: Change camera color HSV mask
2025-10-05 fix: Set camera exposure time to be manual instead of auto
    [main.cpp]
2025-10-05 chore: Change lidar filter
2025-10-05 chore: Change camera HSV color mask
2025-10-05 fix: Make getTrafficLightPoints get the deltaPose to properly transpose the trafficLight points according the the data from the IMU
    [lidar_processor.h, main.cpp]
2025-10-05 fix: Remove robotDeltaPose from combineTrafficLightInfo so that the trafficLight point does not get transpose twice
    [main.cpp]
2025-10-05 fix: Fix obstacle challenge
    [main.cpp]
2025-10-05 fix: Obstacle challenge: make sure that there can't be outer traffic light in the starting section
    [main.cpp]
2025-10-05 ci: Use Docker BuildKit’s built-in GitHub Actions cache
2025-10-05 doc: Add more detailed instructions on mounting electronics.
2025-10-05 doc: Clarify details in step 3 and 4 and add amount specifications to screws
2025-10-08 doc: Change the filename of wiring diagram
2025-10-08 doc: Addjustification for jumper wires in 3.4
2025-10-08 doc: Update wiring diagram picture
2025-10-08 doc: Remove numbering for STL and Slicer files
2025-10-16 doc: Move chassis design to mobility management
2025-10-16 doc: Change specs of LIDAR and specify component type
2025-10-16 doc: Change wording structure of the steering section
2025-10-16 doc: Add placeholder section for transistor and motor driver
2025-10-16 doc: Add power consumption section draft
2025-10-16 doc: Add M.2 HAT+ to power and sense management draft
2025-10-16 doc: Add chassis pic and dimensions
2025-10-16 doc: List motor driver specs
2025-10-19 doc: Move shop link to bill of materials
2025-10-19 doc: Move transistor and motor driver to power section
2025-10-19 doc: Align the back to top button to the right
2025-10-20 doc: Make expandable buttons bigger
2025-10-20 doc: Improve readability of the API Documentation landing page
2025-11-02 doc: Change LIDAR pic
2025-11-02 doc: Change servo from S0004M to S0009M
2025-11-02 doc: Add differential gear section to 2.1
2025-11-24 feat: Change servo to S0009m
    [FrontAssembly.FCStd, FrontCover.FCStd, FrontCover_1x.stl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]
2025-11-24 feat: Re-slice the Linkages
    [CE3V3KE_Linkages.3mf]
2025-11-24 feat: Re-slice the FrontCover
    [CE3V3KE_FrontCover_1x.3mf]
2025-11-24 feat: Change pico2 code to match to new servo
2025-11-24 fix: Move lidarData filtering to the correct place
2025-11-24 fix: Make LidarModule read lidar healy error code when timed out 3 times in a row
2025-11-24 fix: Fix open_challenge backward pid
    [main.cpp]
2025-11-24 fix: Fix obstacle_challenge heading diff calculation
    [main.cpp]
2025-11-24 fix: Start camera logging in obstacle_challenge
    [main.cpp]
2025-11-24 fix: Fix obstacle_challenge backward pid
    [main.cpp]
2025-11-24 fix: Fix traffic light detection issue and CW parking
    [main.cpp]
2025-11-24 fix: Fix CCW parking
    [main.cpp]
2025-11-24 fix: Fix obstacle_challenge traffic light detection issue
    [main.cpp]
2025-11-24 fix: Make obstacle_challenge more stable
    [main.cpp]
2025-11-24 fix: Fix logger issue
    [main.cpp]
2025-11-24 fix: Make CW Unpark better
    [main.cpp]
2025-11-24 fix: Fix camera see parking wall as red and associate that to the traffic light
    [main.cpp]
2025-11-24 fix: Fix scan map
    [main.cpp]
2025-11-24 fix: Make pushing lap not check for traffic lights
    [main.cpp]
2025-11-24 fix: Fix camera HFOV value
    [main.cpp]
